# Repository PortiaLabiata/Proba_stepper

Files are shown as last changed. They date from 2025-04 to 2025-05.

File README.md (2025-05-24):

# Драйвер шаговика

Это прошивка для простого драйвера шагового двигателя, управляемого по UART. 

## TODO

1. Добавить защиту от избыточного тока, отключение тока в этом случае.
2. Добавить защиту от перегрева моста (схемотехническое решение) и контроллера, отключение тока или перезагрузка в этом случае.
3. Добавить защиту от застревания (механическое решение, энкодер), отключение тока в этом случае.
4. Добавить логирование в постоянную память (схемотехническое решение, ЭСППЗУ?).
5. !!! Добавить запись кода ошибки в регистр Modbus !!!

## Modbus

Последняя версия прошивки использует для взаимодействия с компютером протокол Modbus RTU над последовательным интефейсом. Сейчас устройство сконфигурировано на скорость 9600 Бод, 1 стоп-бит и чётный бит чётности. У устройства есть следйющие регистры:

### Holding registers

1. Команда: 0 - нет команды, 1 - вращать двигатель, 2 - остановить двигатель;
2. Число шагов;
3. Режим: 1 байт: 0 - полношаговый однофзный, 1 - полношаговый двухфазный, 2 - полушаговый, 2 байт: 0 - по часовой стрелке, 1 - против часовой стрелки.
4. Скорость: пауза между шагами, мс.

### Input registers

1. Код ошибки/сбоя: если произошла ошибка, не связанная с протоколом, или детектируемый аппаратный сбой, то здесь будет лежать код. Пока не реализовано.

## Структура проекта

1. driver/timer.h - низкоуровневое управление таймерами, в основной ветке не используется.
2. driver/stepper.h - низкоуровневое управление шаговым двигателем, тип дескриптора шаговика, функции обратного вызова.
3. driver/uart.h - низкоуровневое управление UART, тип дескриптора UART, функции обратного вызова.
4. driver/interrupts.h - обработчики прерываний.
5. core/system.h - низкоуровневая инициализация системы, общие константы.
6. core/types.h - тип(ы), которые нужны всем модулям, например системный контекст.
7. utils/service.c - вспомогательные функции, например простая реализация atoi.
8. hardware - схемы отладочной платы.

## Структура system.h

В этом файле находятся функции, конфигурирующие периферию и дерево тактирования, а также несколько вспомогательных функций.

### Дерево тактирования

Используется путь `HSI->/2->PLLx12->AHB/1->APB1/1, APB2/1`, так что `f(SYSCLK)=f(PCLK1)=f(PCLK2)=48MHz`. Во время инициализации один раз выполняются функции `Get_SYSCLKFreq()` и пр., их значения присваиваются глобальным переменным и к ним можно получить через макросы `SYSCLK_FREQ` и пр (см. файл). Это допустимо, так как изменение частоты в рантайме не предусмотрено, а если откажет PLL, то контроллер всё равно не сможет это обнаружить и принять меры.

### TIM2

Для неблокирующего управления двигателем используется TIM2 в базовом режиме, поэтому его инициализация производится здесь. В целом сказать больше нечего.

## Структура uart.h

Файл содержит реализацию драйвера UART, обеспечивающего базовые функции передачи и приема данных с поддержкой прерываний. Основные компоненты:

Структуры данных:

1. `UART_Handle`: Хранит состояние UART (указатель на периферию USART, буфер приема, счетчик оставшихся данных, флаги ошибок и готовности команды).

Инициализация:

1. `UART_Init()`: Инициализирует обработчик UART из глобального пула, настраивает прерывание приема (RXNE). Поддерживает до `MAX_UARTS` экземпляров.

Функции ввода-вывода:

1. `UART_Transmit()`: Блокирующая передача данных с проверкой таймаута. Ожидает флаги TXE (готовность к передаче) и TC (завершение передачи).

2. `UART_Receive()`: Неблокирующий старт приема данных. Устанавливает буфер и размер данных для заполнения через прерывания.

Управление состоянием:

3. Геттеры/сеттеры (`UART_GetCmdRdy`, `UART_SetRxLeft` и др.): Для доступа к флагам готовности команды и счетчику оставшихся данных.

Обработка прерываний:

4. `UART_ReceiveCallback()`: Обрабатывает принятые данные при срабатывании прерывания. Записывает данные в буфер, обновляет курсор и флаг `command_ready` при завершении приема.

## Структура stepper.h

Файл содержит реализацию управления шаговыми двигателями с поддержкой блокирующих и асинхронных операций. Основные компоненты:

Структуры данных:

1. `Stepper_Handle`:

- `gpios`: Указатель на массив GPIO, управляющих катушками двигателя.
- `config`: Массив конфигураций включения катушек для каждого шага (например, для полношагового режима).
- `instance`: Таймер (TIM), используемый для асинхронного управления.
- `config_idx`: Текущий индекс в массиве конфигураций.
- `direc`: Направление вращения.
- `steps_left`: Оставшееся количество шагов (для асинхронного режима).

Инициализация:

1. `Stepper_Init()`:

Инициализирует объект шагового двигателя из глобального пула. Связывает GPIO и конфигурацию катушек, сбрасывает состояние двигателя. Поддерживает до MAX_STEPPERS экземпляров.

Основные функции:

1. `Stepper_Step()`: Выполняет один шаг в заданном направлении. Активирует катушки согласно текущей конфигурации (`config[config_idx]`). Обновляет `config_idx` (инкремент/декремент в зависимости от направления).

2. `Stepper_Halt()`: Останавливает двигатель, отключая катушки (если hold = RESET).

3. `Stepper_Rotate()`: Блокирующий метод вращения на заданное количество шагов. Циклически вызывает `Stepper_Step()` с задержкой del между шагами.

4. `Stepper_Rotate_IT()`: Неблокирующий метод вращения через прерывания таймера.Настраивает таймер TIM2 на генерацию прерываний через интервал `del`. Уменьшает `steps_left` при каждом прерывании.

Обработка прерываний:

1. `TIM_UEV_Callback()`: Вызывается при срабатывании таймера (Update Event):

Выполняет шаг двигателя и уменьшает `steps_left`.
Останавливает таймер при завершении вращения (`steps_left` == 0).

Ограничения:

1. Жесткая привязка к GPIOB (в текущей реализации).
2. Нет проверки ошибок (указано в \todo).

6. Зависимости:

Таймер TIM2 используется для асинхронного управления, конфигурация GPIO должна быть предварительно настроена (направление, режим).

## Переключение катушек с использованием только таймеров

Управлять катушками можно с помощью только таймеров. Сейчас прерывание генерируется в среднем раз в 10 мс, а это довольно часто. Эту проблему можно решить, используя таймеры расширенного управления, а именно регистр `RCR`. Можно генерировать событие обновления не на каждом шаге, а только раз в определённое количество шагов и управлять выводами GPIO с помощью каналов таймера. Тогда прерывание будет генерироваться в худшем случае каждые 256 шагов, то есть в среднем раз в 2.5 с. Однако мне не удалось (пока?) придумать, как создать нужный сигнал с помощью только одного таймера, поэтому можно использовать два. Чтобы генерировать сигналы для полношагового двухфазного режима (самый простой вариант), можно поступить так:
 ```mermaid
 graph TD
    TIM1 --> |CH1| GPIO1
    TIM1 --> |CH2| GPIO2

    TIM1 --> |CH3, TRGO| TIM2
    TIM2 --> |CH1| GPIO3
    TIM2 --> |CH2| GPIO4
```

Каналы 1 и 2 таймера 1 комплементарны, как и каналы 1 и 2 таймера 2. Канал 3 таймера 1 работает в режиме OC Active и создаёт задержку в половину периода для таймера 2, который работает в режиме Trigger. Таким образом создаётся смещение по фазе в 90 градусов между сигналами первого и второго таймера.

Эта идея была отброшена из-за сложности, в данный момент игра не стоит свеч.

## Иерархия проекта в целом

```mermaid
flowchart TD
 subgraph HAL["Hardware Abstraction"]
        clock[("system.c
        ClockConfig()")]
        gpio[("system.c
        GPIO_Config()")]
        tim[("system.c
        TIM2_Config()")]
        uart_conf[("system.c
        UART_Config()")]
  end
 subgraph DRIVERS["Drivers"]
        uart[("uart.c
        UART_Init()
        UART_Transmit()
        UART_Recieve()")]
        stepper[("stepper.c
        Stepper_Init()
        Stepper_Step()
        Stepper_Rotate_IT()")]
  end
 subgraph ISRs["Interrupts"]
        uart_isr[("USART1_IRQHandler
        (UART RX)")]
        tim_isr[("TIM2_IRQHandler
        (Stepper Timing)")]
  end
    main[("main.c
    (Orchestrator)")] -- init --> clock & gpio & tim & uart & stepper & uart_conf
    uart_isr -- fills --> buffer[("Command Buffer
    (volatile uint8_t[10])")]
    buffer -- processed by --> main
    main -- calls --> stepper
    tim_isr -- triggers --> stepper
    stepper -- controls --> gpio

     main:::orange
    classDef orange fill:#f96,stroke:#333
    classDef blue fill:#6af,stroke:#333
    classDef green fill:#5d5,stroke:#333

```

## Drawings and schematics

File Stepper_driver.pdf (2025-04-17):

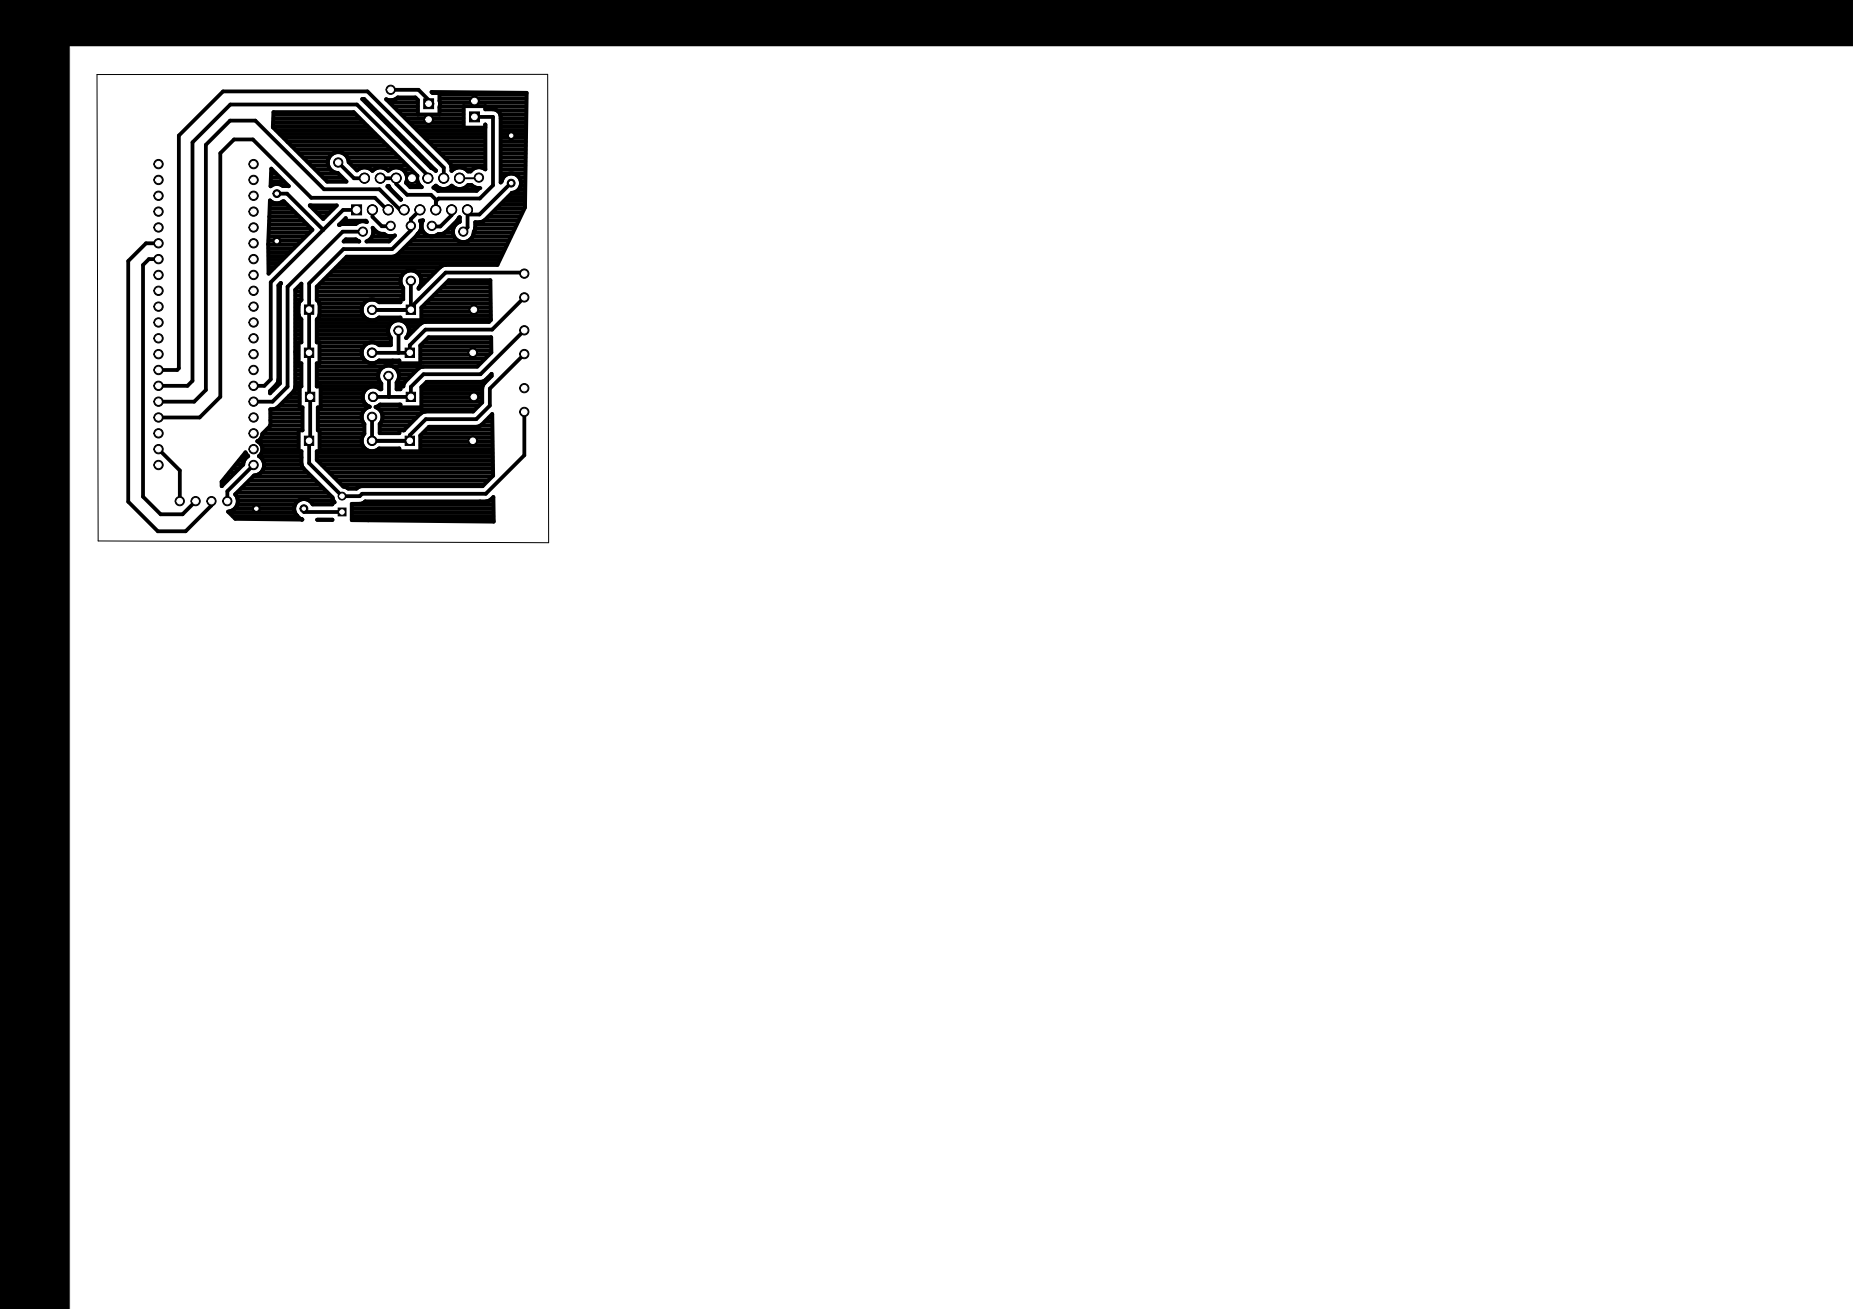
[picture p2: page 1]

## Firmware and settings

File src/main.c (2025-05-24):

#include "main.h"
#include "utils/service.h"
#include "driver/interrupts.h"
#include "driver/uart.h"
#include "driver/stepper.h"
#include "driver/iwdg.h"
#include "driver/spi.h"
#include "driver/enc28j60.h"

#include "app/mb_logic.h"
#include "app/net.h"
#include "uip_arp.h"

#include "mb.h"
#include "port.h"

static System_Status_t eSystemPoll(MB_Proxy_t *proxy); 
#define BUF ((struct uip_eth_hdr *)uip_buf)
volatile uint8_t ppend = RESET;

const uint8_t wave[4] = {
    0b1000,
    0b0010,
    0b0100,
    0b0001
};

const uint8_t wave_full_phase[4] = {
    0b1010,
    0b0110,
    0b0101,
    0b1001
};

const uint32_t gpios[4] = {GPIO_ODR_ODR6, GPIO_ODR_ODR7, GPIO_ODR_ODR8, GPIO_ODR_ODR9};
volatile uint8_t buffer[10];

int main(void) {
    Clock_Config();
    GPIO_Config();
    TIM2_Config();
    TIM3_Config();
    SPI_Config();
    //LOG(strcat(__func__, "All on-chip peripherals initialized."));
    
#if STARTUP_BLINK_ENABLE==1
    STARTUP_BLINK();
#endif

    IWDG_Config();

    Stepper_Handle_t *stp = Stepper_Init(TIM2, gpios, wave, NULL, NULL);
    UART_Handle_t *hnd = UART_Init(USART1);
    
    eMBTCPInit(MB_PORT);
    eMBEnable();

    MB_Proxy_t *proxy = MB_Proxy_Init();
    Context_Init(&ctx, hnd, stp);
    net_init();
    //Stepper_SetMode(stp, STEPPER_MODE_FULLSTEP_1PHASE);

    while (1) {
        eMBPoll();
        eSystemPoll(proxy);
        if (!ETH_INT_STATE()) {
            uip_len = ENC_RecievePacket(uip_buf);
        }
        if (uip_len > 0) {
            if (BUF->type == HTONS(UIP_ETHTYPE_IP)) {
                uip_arp_ipin();
                uip_input();

                if (uip_len > 0) {
                    uip_arp_out();
                    dev_send();
                }

            } else if (BUF->type == HTONS(UIP_ETHTYPE_ARP)) {
                uip_arp_arpin();
                if (uip_len > 0) {
                    dev_send();
                }

            }
        }
        if (timer_expired(&periodic_timer)) {
            for(int i = 0; i < UIP_CONNS; i++) {
                uip_periodic(i);
                if(uip_len > 0) {
                  uip_arp_out();
                  dev_send();
                }
            }
        }

        if(timer_expired(&arp_timer)) {
            timer_reset(&arp_timer);
            uip_arp_timer();
        }
        IWDG_RELOAD();
    }
}

/**
 * \todo Add error handling.
 */
static System_Status_t eSystemPoll(MB_Proxy_t *proxy) {
    MB_Proxy_Unmarshall(proxy);
    System_Status_t status = SYS_OK;
    uint32_t speed = 0;
    switch (MB_Proxy_AccessCmd(proxy)) {
        case CMD_NOCMD:
            break;

        case CMD_ROTATE:
            speed = MB_Proxy_AccessSpeed(proxy);
            if (speed < 10 || speed > 50) {
                MB_Proxy_SetCmd(proxy, CMD_NOCMD);
                status = SYS_ERROR_ILLVALUE;
                break;
            }

            Stepper_SetMode(ctx.stepper_handle, MB_Proxy_AccessMode(proxy));
            Stepper_Rotate_IT(ctx.stepper_handle, MB_Proxy_AccessSteps(proxy), \
                MB_Proxy_AccessDir(proxy), MB_Proxy_AccessSpeed(proxy));
            break;

        case CMD_HALT:
            Stepper_Halt_IT(ctx.stepper_handle, RESET);
            break;
        
        case CMD_INVALID:
            status = SYS_ERROR_ILLVALUE;
            break;
        
        default:
            status = SYS_ERROR;
            break;
    }
    MB_Proxy_SetCmd(proxy, CMD_NOCMD);
    MB_Proxy_Marshall(proxy);
    return status;
} 

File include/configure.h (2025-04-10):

#pragma once
#include "main.h"
#include "service.h"

/* Magic numbers */

#define GPIO_MODE_OUTPUT 0b10UL
#define GPIO_OUTPUT_PP   0b00UL
#define GPIO_OUTPUT_OD   0b01UL
#define GPIO_INPUT_P     0b10UL

#define HSI_FREQ         8000000 // Hz
#define HSE_FREQ         16000000 // I don't have it, may vary
/* Since frequency is not intended to change during runtime, this approach is better,
since it calculates the f-s only once on startup. */
#define SYSCLK_FREQ      _sysclk_freq
#define AHB_FREQ         _ahb_freq
#define PCLK2_FREQ       _pclk2_freq
#define PCLK1_FREQ       _pclk1_freq

/* Global definitions */

extern uint32_t _sysclk_freq;
extern uint32_t _ahb_freq;
extern uint32_t _pclk2_freq;
extern uint32_t _pclk1_freq;

/* General configuration */

void ClockConfig(void);
void GPIO_Config(void);
void UART_Config(void);
void TIM3_Config(void);

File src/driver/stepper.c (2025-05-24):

#include "driver/stepper.h"

/* Typedefs */

/**
 * \todo Microoptimization: switch from array to single variables. It will make time
 * of reading a value just a little bit shorter.
 */
struct Stepper_Handle {
    const uint32_t *gpios;
    const uint8_t *config;
    TIM_TypeDef *instance;
    volatile uint8_t config_idx;
    uint8_t direc;
    volatile uint32_t steps_left;
    uint8_t mode;

    const uint8_t *config_1ph;
    const uint8_t *config_2ph;
    const uint8_t *config_half;
};

/* Handle pool */

static Stepper_Handle_t _stepper_pool[MAX_STEPPERS];
static uint8_t _n_steppers;

/* Functions */

/**
 * \brief Initializes stepper object from the global pool.
 * \param[in] gpios Array of GPIO pins used for stepper.
 * \param[in] configs Array of sequential configurations of stepper GPIO pins.
 * \returns Pointer to a stepper object. Unsafe, btw.
 */
Stepper_Handle_t *Stepper_Init(TIM_TypeDef *inst, const uint32_t *gpios, const uint8_t *config_1ph, const uint8_t *config_2ph, \
    const uint8_t *config_half) {
    if (_n_steppers >= MAX_STEPPERS) return NULL;
    
    Stepper_Handle_t *stp = &_stepper_pool[_n_steppers++];
    stp->gpios = gpios;
    stp->config = config_1ph;
    stp->instance = inst;

    stp->config_1ph = config_1ph;
    stp->config_2ph = config_2ph;
    stp->config_half = config_half;

    stp->config_idx = 0;
    stp->mode = STEPPER_MODE_FULLSTEP_1PHASE;

    GPIOB->ODR &= ~(gpios[0] | gpios[1] | gpios[2] | gpios[3]);
    return stp;
}

/**
 * \brief Sets the stepper mode, either full step 1 phase, full step 2 phase of half step.
 * \param[in] stp Stepper handle.
 * \param[in] mode Stepper mode, either STEPPER_MODE_FULLSTEP_1PHASE, STEPPER_MODE_FULLSTEP_2PHASE,
 * or STEPPER_MODE_HALFSTEP.
 * \returns Operation status.
 */
Stepper_Status_t Stepper_SetMode(Stepper_Handle_t *stp, Stepper_Mode_t mode) {
    switch (mode) {
        case STEPPER_MODE_FULLSTEP_1PHASE:
            STEPPER_LEAVE_ON_NULL(stp->config_1ph);
            stp->config = stp->config_1ph;
            break;
        case STEPPER_MODE_FULLSTEP_2PHASE:
            STEPPER_LEAVE_ON_NULL(stp->config_2ph);
            stp->config = stp->config_2ph;
            break;
        case STEPPER_MODE_HALFSTEP:
            STEPPER_LEAVE_ON_NULL(stp->config_half);
            stp->config = stp->config_half;
            break;
        default:
            return STEPPER_ERROR_SOFT;
    }
    stp->mode = mode;
    return STEPPER_OK;
}

/**
 * \brief Preforms a single step.
 * \param[in] stp Stepper handle.
 * \param[in] dir Direction, can be either CLOCKWISE or COUNTERCLOCKWISE.
 * \returns Operation status.
 */
Stepper_Status_t Stepper_Step(Stepper_Handle_t *stp, uint8_t dir) {
    uint8_t curr_config = stp->config[stp->config_idx];
    GPIOB->ODR &= ~(stp->gpios[0] | stp->gpios[1] | stp->gpios[2] | stp->gpios[3]);
    int n_entries = sizeof(stp->config) / sizeof(char);

    if (curr_config & 0b0001) GPIOB->ODR |= stp->gpios[3];
    if (curr_config & 0b0010) GPIOB->ODR |= stp->gpios[2];
    if (curr_config & 0b0100) GPIOB->ODR |= stp->gpios[1];
    if (curr_config & 0b1000) GPIOB->ODR |= stp->gpios[0];

    if (dir == CLOCKWISE) {
        stp->config_idx = (stp->config_idx + 1) % n_entries;
    } else if (dir == COUNTERCLOCKWISE) {
        stp->config_idx = (stp->config_idx - 1 + n_entries) % n_entries;
    } else {
        return STEPPER_ERROR_SOFT; // In case something went horribly wrong.
    }
    return STEPPER_OK;
}

/**
 * \brief Halts a stepper motor and either leaves it energized 
 * (huge current consumption!) or not.
 * \param[in] stp Stepper handle.
 * \param[in] hold Leave the coils energized or not, either SET or RESET.
 * \returns Operation status.
 */
Stepper_Status_t Stepper_Halt(Stepper_Handle_t *stp, uint8_t hold) {
    if (!hold) {
        GPIOB->ODR &= ~(stp->gpios[0] | stp->gpios[1] | stp->gpios[2] | stp->gpios[3]);
        return STEPPER_OK;
    } else {
        return STEPPER_OK;
    }
}


/**
 * \brief Performs a blocking stepper revolution. Currently only full step mode supported.
 * Minimum delay is 10 ms, technically there is no maximum delay, but at 100 ms the
 * current cunsomption increases to 300 mA, so I would say a max of 50-70 ms is recommended.
 * \param[in] stp Stepper handle.
 * \param[in] steps Number of steps performed.
 * \param[in] dir Direction, can be either CLOCKWISE or COUNTERCLOCKWISE.
 * \param[in] del Delay between steps.
 * \returns Operation status.
 * \todo Add error handling.
 */
Stepper_Status_t Stepper_Rotate(Stepper_Handle_t *stp, uint32_t steps, uint8_t dir, uint32_t del) {
    for (int i = 0; i < steps; i++) {
        Stepper_Step(stp, dir);
        delay(del);
    }

    return STEPPER_OK;
}

/**
 * \brief Performs a non-blocking stepper revolution. Currently only full step mode supported.
 * Minimum delay is 10 ms, technically there is no maximum delay, but at 100 ms the
 * current cunsomption increases to 300 mA, so I would say a max of 50-70 ms is recommended.
 * \param[in] stp Stepper handle.
 * \param[in] steps Number of steps performed.
 * \param[in] dir Direction, can be either CLOCKWISE or COUNTERCLOCKWISE.
 * \param[in] del Delay between steps.
 * \returns Operation status.
 * \todo Add error handling.
 */
Stepper_Status_t Stepper_Rotate_IT(Stepper_Handle_t *stp, uint32_t steps, uint8_t dir, uint32_t del) {
    stp->steps_left = steps;
    stp->direc = dir;

    stp->instance->PSC = PCLK1_FREQ / 1000 - 1;
    stp->instance->ARR = del - 1;
    stp->instance->EGR |= TIM_EGR_UG;
    stp->instance->CR1 |= TIM_CR1_CEN;
    return STEPPER_OK;
}

/**
 * \brief Halts stepper in non-blocking mode analogous to blocking case.
 * \param[in] stp Stepper handle.
 * \param[out] hold Leave the coild energized or not, either SET or RESET.
 * \returns Operation status.
 */
Stepper_Status_t Stepper_Halt_IT(Stepper_Handle_t *stp, uint8_t hold) {
    stp->steps_left = 0;
    return Stepper_Halt(stp, hold);
}

/* Callbacks */

/**
 * \brief Callback for timer UEV, steps the stepper from the system context.
 * \param[in] ctx System context.
 * \returns Operation status, either SET or RESET. The IRS will decide if it's time to
 * stop the timer by the return value, so low-level and driver-level modules are separated.
 */
uint8_t TIM_UEV_Callback(System_Context_t *ctx) {
    Stepper_Handle_t *handle = ctx->stepper_handle;
    if (handle->steps_left > 0) {
        Stepper_Step(handle, handle->direc);
        handle->steps_left--;
        return SET;
    } else {
        Stepper_Halt(handle, RESET);
        return RESET;
    }
}

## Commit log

2025-04-09 Добавлены файлы железа
2025-04-09 Обновлена плата
2025-04-10 Изменена структура и добавлен код
2025-04-10 Изменена структура
2025-04-10 Исправлена ошибка в индексах в Stepper_Step, теперь всё работает
    [main.c, stepper.c]
2025-04-10 Добавлено неблокирующее вращение
2025-04-10 Добавлена простейшая обработка команд, но пока не протестирована
2025-04-10 Обработка доделана
2025-04-11 Простейшие комманды оттестированы
2025-04-11 Последние фиксы перед реструктуризацией
2025-04-11 Полная реструктуризация проекта сделана
2025-04-11 Вся структура переработана, какой ужас
2025-04-11 Некоторые фиксы
2025-04-12 Небольшие фиксы
2025-04-12 Добавлена документация
2025-04-12 В README вставлена диаграмма
2025-04-12 Диаграмма исправлена
2025-04-12 README снова исправлен
2025-04-13 Драйвер CAN?
2025-04-15 Макет готов
2025-04-15 TIM3 удалён
2025-04-15 Макет точно полностью готов
2025-04-15 UART починен
2025-04-16 Всё работает, но не очень нужно
2025-04-16 Всё подготовлено для мерджа
2025-04-16 Всё исправлено, готово к дальнейшим шагам
    [interrupts.c, main.c, stepper.c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]
2025-04-17 Удалён ненужный файл
2025-04-22 Добавлена заготовка для драйвера и файл конфигурации
2025-04-22 IWDG вроде как работает, но почему-то не записывается прескейлер
2025-04-22 Минимальная рабочая реализация, прескейлер всё ещё не работает
2025-04-22 Поддержка режимов добавлена
2025-04-23 Некоторые функции перенесены в более логичные модули
2025-04-23 Ура, варнингов больше нет
2025-04-23 Добавлена обработка ошибок в atoi
2025-04-25 Десктопное приложение неожиданно готово
2025-04-25 Доделано декстопное приложение и переделан IO с кампутером
2025-04-27 Добавлены функции логирования
2025-04-28 Изменения по ходу дела
2025-05-23 Добавлен файл схемы нового прототипа
2025-05-24 Первый коммит этой ветки, возможно стоит вообще вынести это в отдельный реп
2025-05-24 Базовые функции Modbus CB работает
2025-05-24 Доделаны CB и добавлена логика системы
2025-05-24 Дополнен README
2025-05-24 Исправлен Readme
2025-05-24 Добавлено задание режима
2025-05-24 Исправлены разные недочёты и удалены ненужные части кода
    [main.c, prefs.h, system.c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]
2025-05-24 Добавил прокси, пока не тестировал
2025-05-24 Штош, этот коммит - кошмар любого ревьюера. Как хорошо, что мой код никто не рвьюит
2025-05-24 Ну, по крайней мере оно собирается
2025-05-24 Штош, теперь оно точно собирается
2025-05-24 Заменяю библотеку TCP/IP-стека
2025-05-24 Обновлена конфигурация
2025-05-24 Пока что компилируется
2025-05-24 Предварительный драйвер вроде готов
2025-05-24 Драйвер SPI готов
2025-05-24 База драйвера работает
2025-05-24 Добавлена куча регистров, масок и команд
2025-05-24 Инициализация (почти) закончена
2025-05-24 WBM, RBD, WCR, RCR предположительно работают
2025-05-24 MAC работает, заголовок правильный
2025-05-24 Добавлен скрипт для тестирования приёма
2025-05-24 Кажется, RX работает
2025-05-24 Ну вроде драйвер работает
2025-05-24 Пинг работает, но зависает
2025-05-24 Пофикшен баг с зависанием приёма и добавлена обработка "прерывания"
2025-05-24 Есть баг, связанный видимо с кремнием
2025-05-24 Проблема решена
2025-05-24 Всё работает
2025-05-24 Коммит перед большим мерджем
2025-05-24 Добвлено много блоков
